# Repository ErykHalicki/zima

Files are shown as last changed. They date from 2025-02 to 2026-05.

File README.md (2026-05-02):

# Zima: Low-Cost Imitation Learning Robot

Zima is a custom-built rover with a 5-DOF arm, designed as a personal research platform for imitation learning in robotic manipulation. It uses teleoperated demonstrations to train vision-based policies that map camera observations directly to motor actions.

[Devlog](https://eryk.ca/zima_devlog.html) | [Dataset](https://huggingface.co/datasets/ehalicki/zima-rubiks-cube)


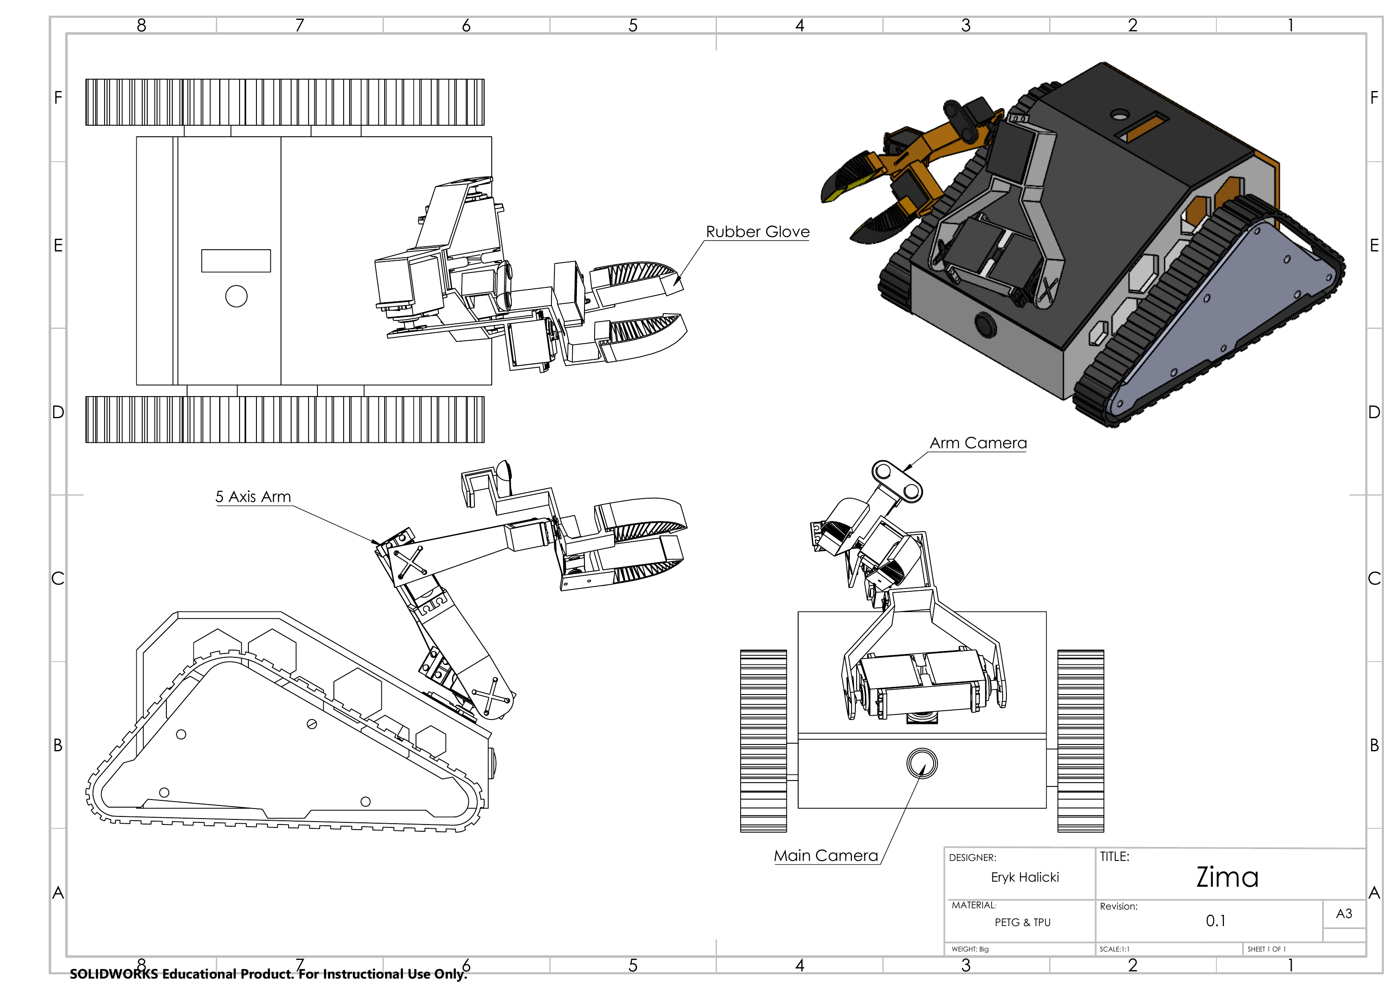
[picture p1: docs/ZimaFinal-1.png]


## Current Status
- Hardware prototype operational (5-DOF arm + tracked differential drive base)
- ROS2 control stack deployed on Raspberry Pi 5
- LeRobot integration for teleoperation, dataset recording, and training
- Training and evaluating manipulation policies (ACT, VLAs, world action models, etc.)
- Datasets hosted on HuggingFace with online visualization

## Hardware
- **Arm**: 4x MG996R servo joints + 1x gripper servo, custom forward/inverse kinematics solver
- **Base**: Modified Recon 6.0 Rover chassis, 2x DC motors with rotary encoders
- **Cameras**: Wrist-mounted + front-facing USB RGB (480x640)
- **Compute**: Raspberry Pi 5 (vision + policy execution), ESP32 (hardware interfacing)
- **CAD**: Custom 3D-printed parts designed in FreeCAD (`cad_models/`)

## Repository Structure
```
src/
  firmware/                              # ESP32 motor/servo control (Arduino)
  zima_ros2/
    zima_controls/                       # Arm kinematics solver & controller
    zima_hardware_integration/           # Serial, TCP, camera, and joystick interfaces
    zima_launch/                         # ROS2 launch configurations
    zima_msgs/                           # Custom message types (ArmStateDelta, MotorCommand, etc.)
  lerobot_robot_zima_robot/              # LeRobot Robot interface (TCP to hardware)
  lerobot_teleoperator_zima_ps3_teleop/  # PS3 gamepad teleoperator plugin
  scripts/                              # Bash scripts for recording, training, teleoperation
  legacy/                               # Deprecated ML/simulation code
cad_models/                             # FreeCAD design files
docs/                                   # Circuit diagrams
```

## Architecture

```
PS3 Controller ──► LeRobot Teleoperator ──► TCP ──► ROS2 (Pi 5) ──► Serial ──► ESP32 ──► Motors/Servos
                                                        │
                                                   Cameras ──► Observations
                                                        │
                                              LeRobot Dataset ──► HuggingFace Hub
                                                        │
                                                 Policy Training ──► Deployment
```

**Control flow**: The ESP32 handles low-level servo/motor control over serial. ROS2 nodes on the Pi manage kinematics, camera streaming, and a TCP server (port 5000) that bridges LeRobot to the hardware. The LeRobot framework handles teleoperation input, dataset recording, policy training, and inference.

**Kinematics**: Custom solver using YAML-defined link parameters, numerical IK with KD-tree initialization, and safety collision checks against predefined bounding boxes. Configuration in `src/zima_ros2/src/zima_controls/config/`.

## Usage

Teleoperate the robot:
```bash
lerobot-teleoperate --robot.type=zima_robot --robot.address=192.168.2.5
```

Record a dataset:
```bash
lerobot-record --robot.type=zima_robot --teleop.type=zima_ps3_teleop \
  --dataset.repo_id=ehalicki/zima-rubiks-cube --dataset.num_episodes=10
```

Train a policy:
```bash
lerobot-train --dataset.repo_id=ehalicki/zima-rubiks-cube \
  --policy.type=act --policy.device=mps
```

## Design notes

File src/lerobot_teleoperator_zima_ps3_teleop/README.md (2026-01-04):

# Zima PS3 Teleoperator

PS3 controller teleoperation interface for the Zima robot, compatible with the LeRobot framework.

## Installation

```bash
cd lerobot_teleoperator_zima_ps3_teleop
pip install -e .
```

## Usage

### With LeRobot CLI

```bash
lerobot-teleoperate \
    --robot.type=zima_robot \
    --robot.address=10.0.0.100 \
    --robot.port=5000 \
    --teleop.type=zima_ps3_teleop
```

### Control Scheme

The control scheme matches the ROS2 joy_control node exactly:

#### Track Control (D-Pad)
- **D-Pad Up**: Move forward
- **D-Pad Down**: Move backward
- **D-Pad Left**: Turn left
- **D-Pad Right**: Turn right

#### Arm Control (Analog Sticks)
- **Left Stick X-axis**: Arm position Y (left/right)
- **Left Stick Y-axis**: Arm position X (forward/back)
- **Right Stick X-axis**: Arm rotation X (roll, inverted)
- **Right Stick Y-axis**: Arm position Z (up/down)

#### Gripper Control
- **L2 Trigger**: Close gripper
- **R2 Trigger**: Open gripper

## Configuration Parameters

- `deadzone`: Analog stick deadzone (default: 0.15)
- `max_speed`: Maximum track speed multiplier (default: 1.0)
- `max_arm_delta`: Maximum arm position delta (default: 1.0)
- `max_rotation_delta`: Maximum arm rotation delta (default: 1.0)

## Requirements

- Python 3.10+
- LeRobot framework
- pygame (for gamepad support)
- PS3 controller (or compatible gamepad)

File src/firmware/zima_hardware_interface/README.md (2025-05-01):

# Zima Hardware Interface

## Overview

The Zima Hardware Interface is a modular Arduino sketch designed to control multiple hardware components for the Zima robotic platform, including:
- Servo Motors (8 channels)
- Rotary Encoders (2 channels)
- DC Motors (2 channels)

## Hardware Bootup Considerations

### EN Pin Capacitor Fix

**Important Hardware Modification:**
- Add a 1µF capacitor between EN and GND
- This resolves intermittent bootup issues with the ESP32
- Helps stabilize the chip during power-on sequence
- Prevents random boot failures or serial communication problems

#### Recommended Capacitor Specification
- Capacitance: 1 µF (microfarad)
- Voltage Rating: 6.3V or higher
- Type: Ceramic or Electrolytic

### Bootup Sequence Notes
- Ensure stable power supply
- Use the recommended EN pin capacitor
- Verify all connections before powering on

## Other Documentation Sections Remain the Same... 

(Rest of the previous README content)

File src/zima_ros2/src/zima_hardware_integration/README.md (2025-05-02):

# Hardware Integration Package

This package provides a ROS2 interface for the Zima robot hardware. It handles serial communication with the ESP32 microcontroller, converting between ROS2 messages and the serial command format used by the hardware interface.

## Architecture

The hardware integration is split into three nodes:

1. **Serial Receiver Node** (`serial_receiver`): Reads data from the serial port and publishes it as ROS2 messages
2. **Serial Sender Node** (`serial_sender`): Receives hardware commands and sends them to the hardware via serial port
3. **Command Generator Node** (`command_generator`): Converts high-level ROS2 messages (e.g., JointState) to hardware commands

## Message Types

The hardware integration uses custom message types defined in the `zima_msgs` package:

- `ServoCommand`: Command for a single servo motor
- `MotorCommand`: Command for DC motors (forward, reverse, stop)
- `EncoderData`: Data from wheel encoders
- `ServoPositions`: Current positions of all servo motors
- `HardwareCommand`: Low-level command for any hardware subsystem
- `HardwareStatus`: Status data from all hardware subsystems

## Usage

### Launch the Complete System

```bash
ros2 launch hardware_integration hardware_interface.py
```

### Launch with Custom Parameters

```bash
ros2 launch hardware_integration hardware_interface.py serial_port:=/dev/ttyACM0 baud_rate:=115200 update_rate:=100.0
```

### Running Individual Nodes

```bash
# Run the serial receiver node
ros2 run hardware_integration serial_receiver

# Run the serial sender node
ros2 run hardware_integration serial_sender

# Run the command generator node
ros2 run hardware_integration command_generator
```

## Topics

### Published Topics

- `/hardware_status` (zima_msgs/HardwareStatus): Complete hardware status
- `/encoder_data` (zima_msgs/EncoderData): Encoder data from wheels
- `/servo_positions` (zima_msgs/ServoPositions): Current servo positions

### Subscribed Topics

- `/joint_states` (sensor_msgs/JointState): Joint state commands for servos
- `/servo_command` (zima_msgs/ServoCommand): Direct servo commands
- `/motor_command` (zima_msgs/MotorCommand): DC motor commands
- `/hardware_command` (zima_msgs/HardwareCommand): Low-level hardware commands

## Parameters

- `serial_port` (string, default: '/dev/ttyUSB0'): Serial port for hardware communication
- `baud_rate` (int, default: 115200): Baud rate for serial communication
- `timeout` (double, default: 0.1): Serial read/write timeout in seconds
- `update_rate` (double, default: 50.0): Rate in Hz for reading from the serial port

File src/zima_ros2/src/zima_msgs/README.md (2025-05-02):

# Zima Messages Package

This package defines custom ROS2 message types for the Zima robot hardware interface.

## Message Types

### ServoCommand

Command for a single servo motor:
- `std_msgs/Header header`: Standard ROS header
- `uint8 servo_id`: ID of the servo (0-7)
- `float32 position`: Position in degrees (0-180)

### MotorCommand

Command for DC motors:
- `std_msgs/Header header`: Standard ROS header
- `uint8 motor_id`: Which motor (MOTOR_LEFT=0, MOTOR_RIGHT=1)
- `uint8 action`: Action (ACTION_FORWARD=0, ACTION_REVERSE=1, ACTION_STOP=2)
- `int32 speed`: Speed value (0-255 for forward/reverse, 0 or 1 for stop)

### EncoderData

Data from wheel encoders:
- `std_msgs/Header header`: Standard ROS header
- `int32 left_clicks`: Encoder clicks for left wheel
- `int32 right_clicks`: Encoder clicks for right wheel

### ServoPositions

Current positions of all servo motors:
- `std_msgs/Header header`: Standard ROS header
- `float32[] positions`: Current positions of all servos (array of 8 values)

### HardwareCommand

Low-level command for any hardware subsystem:
- `std_msgs/Header header`: Standard ROS header
- `uint8 subsystem`: The subsystem ID (0-13)
- `float32 value`: The command value

Subsystem mapping:
- 0-7: Servo motors (position in degrees)
- 8: Left DC Motor Forward (speed 0-255)
- 9: Left DC Motor Reverse (speed 0-255)
- 10: Left DC Motor Stop (0 or 1)
- 11: Right DC Motor Forward (speed 0-255)
- 12: Right DC Motor Reverse (speed 0-255)
- 13: Right DC Motor Stop (0 or 1)

### HardwareStatus

Status data from all hardware subsystems:
- `std_msgs/Header header`: Standard ROS header
- `int32 clicks_left`: Left encoder clicks
- `int32 clicks_right`: Right encoder clicks
- `float32[] servo_positions`: Array of 8 servo positions

## Usage

To use these messages in your ROS2 package, add a dependency in your `package.xml`:

```xml
<depend>zima_msgs</depend>
```

And include the message headers in your C++ code:

```cpp
#include "zima_msgs/msg/servo_command.hpp"
#include "zima_msgs/msg/motor_command.hpp"
// etc.
```

Or import them in your Python code:

```python
from zima_msgs.msg import ServoCommand, MotorCommand
# etc.
```

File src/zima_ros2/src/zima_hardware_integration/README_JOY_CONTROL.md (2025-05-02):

# Joystick Control for Zima Robot

This document describes how to use a PS3 controller to drive the Zima robot.

## Overview

The joystick control system uses the ROS2 `joy` package to receive controller input and converts it to motor commands for the Zima robot. The controller can be used to drive the robot in differential drive mode, where the left joystick controls both forward/backward movement and turning.

## Hardware Requirements

- PS3 compatible controller (or knockoff)
- USB connection or Bluetooth capability
- Zima robot with ESP32 running zima_hardware_interface

## Default Mappings

### Button Mappings
- **X Button**: Button 0
- **Circle Button**: Button 1
- **Triangle Button**: Button 2
- **Square Button**: Button 3
- **L1 Button**: Button 4
- **R1 Button**: Button 5
- **L2 Button**: Button 6
- **R2 Button**: Button 7
- **Select Button**: Button 8
- **Start Button**: Button 9
- **PS Button**: Button 10
- **L3 Button** (Left Stick Press): Button 11
- **R3 Button** (Right Stick Press): Button 12
- **D-Pad Up**: Button 13
- **D-Pad Down**: Button 14
- **D-Pad Left**: Button 15
- **D-Pad Right**: Button 16

### Axis Mappings
- **Left Stick X-Axis**: Axis 0 (left/right)
- **Left Stick Y-Axis**: Axis 1 (up/down)
- **L2 Trigger**: Axis 2 (-1 when pressed, 1 when released)
- **Right Stick X-Axis**: Axis 3 (left/right)
- **Right Stick Y-Axis**: Axis 4 (up/down)
- **R2 Trigger**: Axis 5 (-1 when pressed, 1 when released)

### Control Functions
- **Left Joystick**: Control movement (forward/backward/turning)
- **R1 Button**: Enable motor control (must be held down)
- **R2 Button**: Emergency stop (all motors)
- **Select Button**: Cycle through control modes (drive, arm, custom1, custom2)

## Installation

1. Make sure the ROS2 joy package is installed:
   ```bash
   sudo apt-get update
   sudo apt-get install ros-humble-joy
   ```

2. Build the package:
   ```bash
   cd ~/Desktop/zima/src/ros2_ws
   colcon build --packages-select hardware_integration
   source install/setup.bash
   ```

## Usage

1. Connect your PS3 controller to your computer via USB or Bluetooth
2. Verify the controller is detected:
   ```bash
   ls -l /dev/input/js*
   ```

3. Test your controller mapping (optional but recommended):
   ```bash
   ros2 launch hardware_integration joy_tester.py
   ```
   Press buttons and move joysticks to see their corresponding indices displayed in the terminal.

4. Launch the joystick control system:
   ```bash
   ros2 launch hardware_integration joy_control.py
   ```
   
5. Control your robot:
   - Hold down R1 (button 5) to enable movement control
   - Use the left joystick to drive the robot
   - Press R2 (button 7) for emergency stop
   - Press Select (button 8) to cycle through control modes

## Parameters

The following parameters can be configured when launching:

- `joy_dev`: Joystick device path (default: `/dev/input/js0`)
- `joy_deadzone`: Deadzone for joystick inputs (default: `0.05`)
- `max_speed`: Maximum motor speed (default: `255`)
- `serial_port`: Serial port for hardware communication (default: `/dev/ttyUSB0`)
- `baud_rate`: Baud rate for serial communication (default: `115200`)

Example with custom parameters:
```bash
ros2 launch hardware_integration joy_control.py joy_dev:=/dev/input/js1 max_speed:=200
```

## Node Details

### joy_control_node

This node subscribes to `/joy` topic and publishes to `/motor_command` topic. It performs the following:

1. Reads joystick inputs for linear and angular movement
2. Applies deadzone and scaling
3. Calculates differential drive values for left and right motors
4. Publishes appropriate MotorCommand messages

The node only sends commands when the enable button (R1) is pressed, providing a safety feature.

## Troubleshooting

1. **Controller not detected**: 
   - Check the device path with `ls -l /dev/input/js*`
   - Update the joy_dev parameter with the correct path

2. **Motors not responding**:
   - Verify that you're holding the R1 button while moving the joystick
   - Check that the serial connection is working
   - Ensure the ESP32 is powered and running the correct firmware

3. **Unexpected movement**:
   - Adjust the deadzone parameter if the robot moves when the stick is at rest
   - Reduce max_speed if the robot moves too quickly
   - Check the orientation of the controller (joystick axes may be different)

## Control Modes

The joystick controller supports multiple control modes that can be cycled through using the Select button:

### 1. Drive Mode (Default)
- **Left Joystick**: Controls differential drive movement
  - Y-axis: Forward/backward movement
  - X-axis: Left/right turning
- **R1 Button**: Must be held to enable movement (safety feature)
- **R2 Button**: Emergency stop

### 2. Arm Mode
Reserved for future arm control implementation. When implemented, this mode will allow:
- Controlling servo positions for robotic arm joints
- Precise positional control
- Grip control

### 3. Custom Mode 1
Reserved for future custom control implementation.

### 4. Custom Mode 2
Reserved for future custom control implementation.

## Extensibility

The control system is designed to be easily extended. The codebase includes empty function placeholders for:

- `process_arm_commands()`: For controlling robot arm servos
- `process_custom1_commands()` & `process_custom2_commands()`: For custom control schemes
- `handle_dpad_inputs()`: For D-pad control functions
- `handle_shape_buttons()`: For X, Circle, Triangle, Square button actions
- `handle_trigger_buttons()`: For secondary L1/L2/R1/R2 functions
- `handle_thumbstick_buttons()`: For L3/R3 button press actions

To extend functionality, edit the joy_control.py file and implement these functions according to your needs.

These can be added to the joy_control.py file by adding new parameters and updating the joy_callback method.

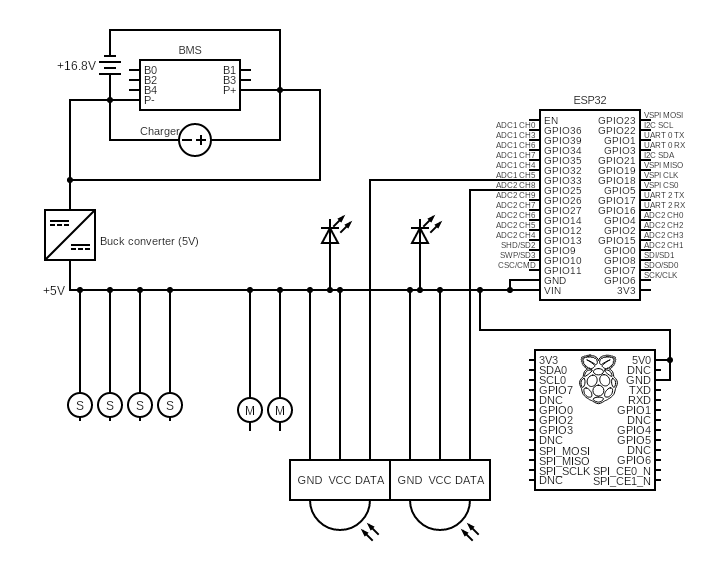
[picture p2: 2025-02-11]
docs/circuit.png

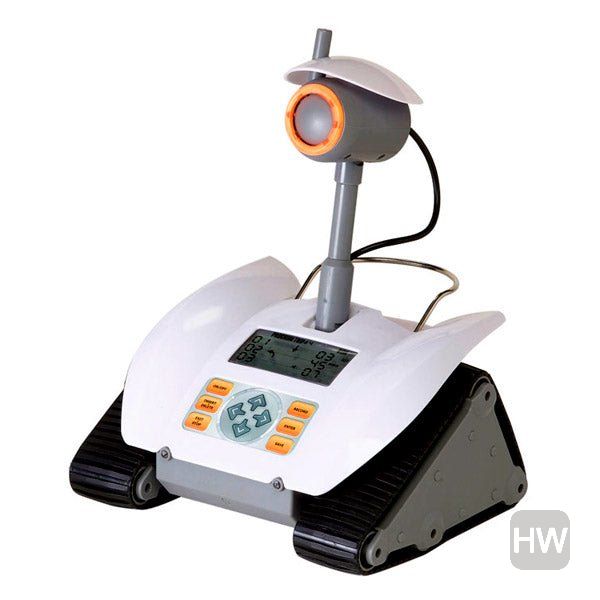
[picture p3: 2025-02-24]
docs/toy.jpeg

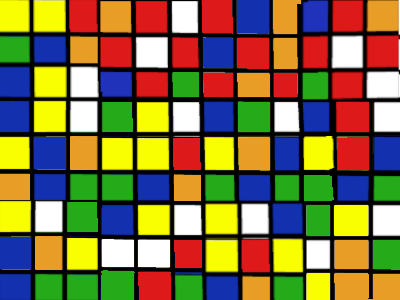
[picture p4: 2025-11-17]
src/imitation_learning/sim/scenes/textures/rubiks.png

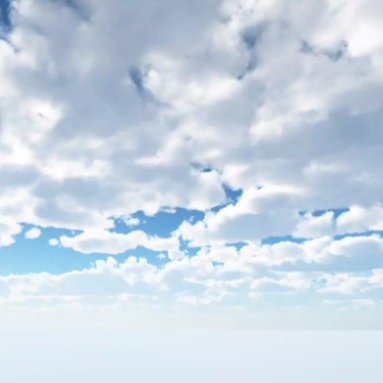
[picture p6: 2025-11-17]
src/imitation_learning/sim/scenes/textures/sky.png

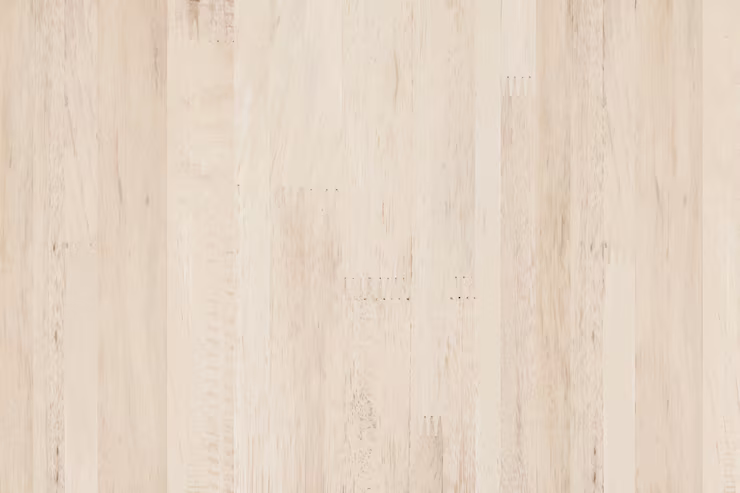
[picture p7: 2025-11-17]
src/imitation_learning/sim/scenes/textures/floorboard.png

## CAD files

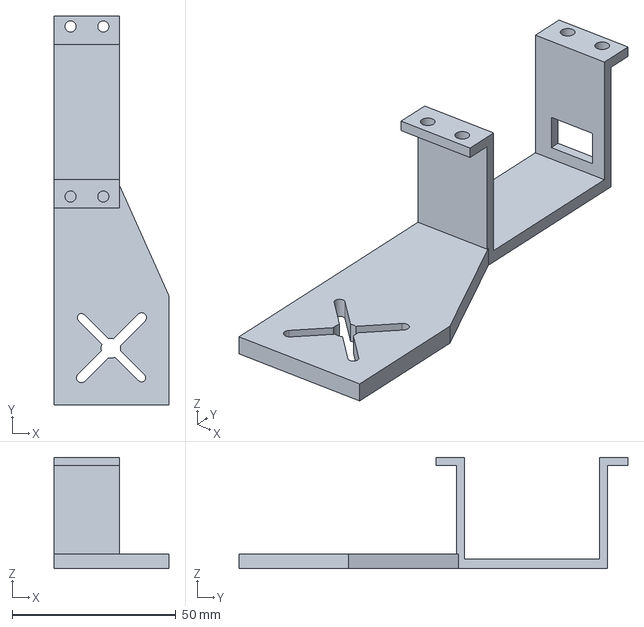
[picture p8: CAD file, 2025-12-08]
cad_models/zima_arm_elbow_to_wrist.FCStd
35.0 x 118.8 x 34.0 mm

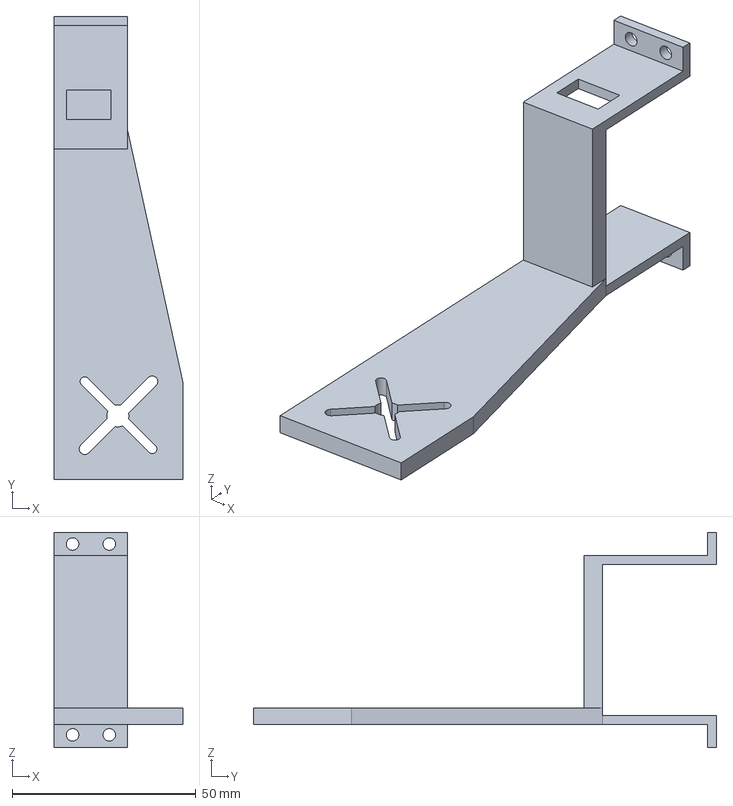
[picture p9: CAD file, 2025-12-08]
cad_models/zima_arm_wrist_to_handv2.FCStd
35.0 x 126.0 x 58.7 mm

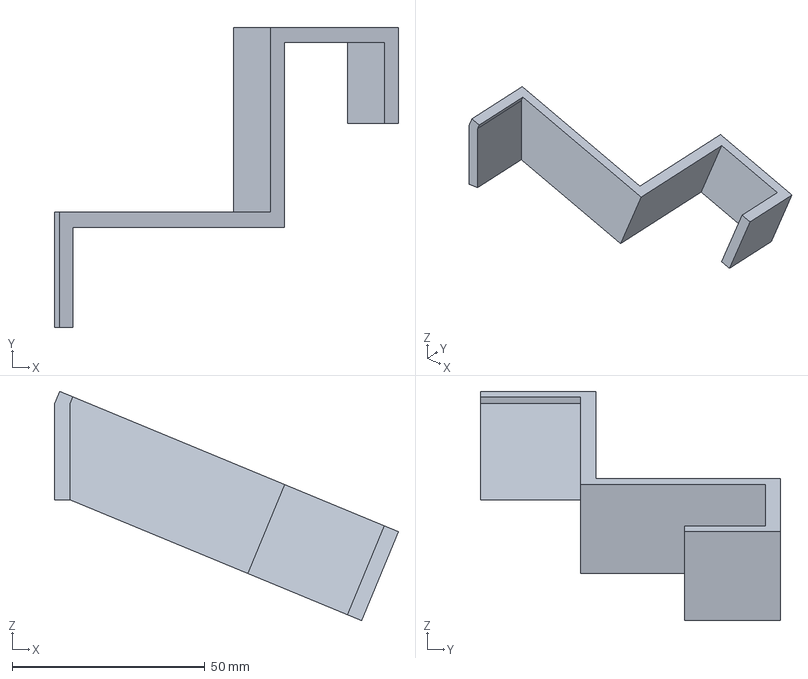
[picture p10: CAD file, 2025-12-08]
cad_models/zima_camera_mount.FCStd
89.4 x 78.0 x 59.6 mm

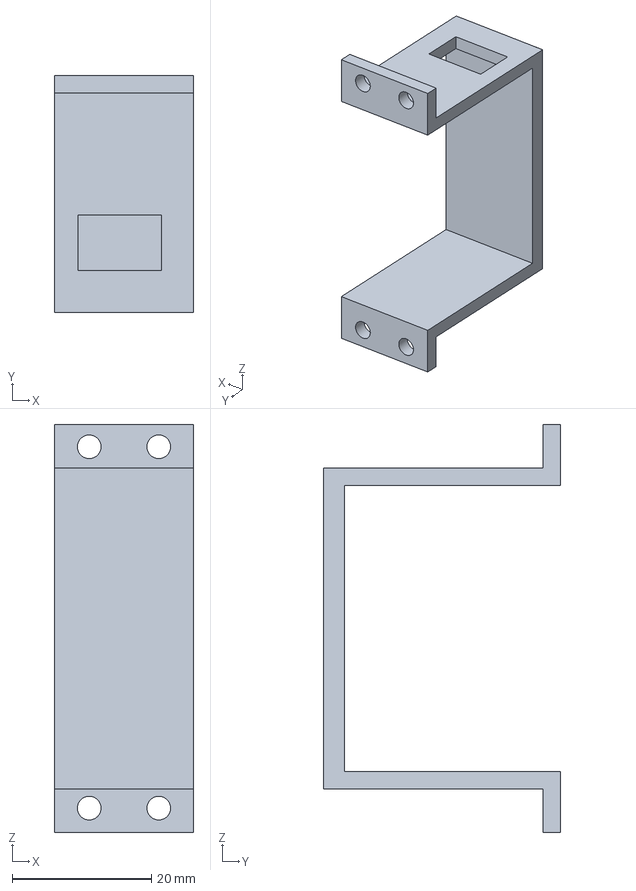
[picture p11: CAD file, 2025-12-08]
cad_models/996R_Mount.FCStd
20.0 x 34.0 x 58.7 mm

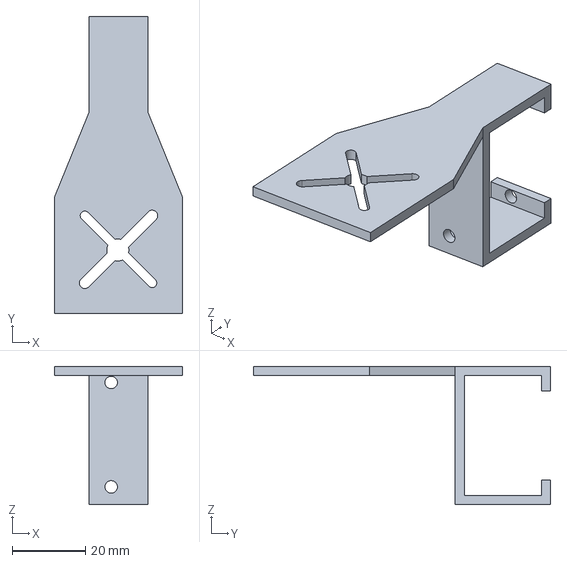
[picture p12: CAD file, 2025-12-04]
cad_models/zima_arm_wrist_to_hand.FCStd
35.0 x 81.0 x 37.7 mm

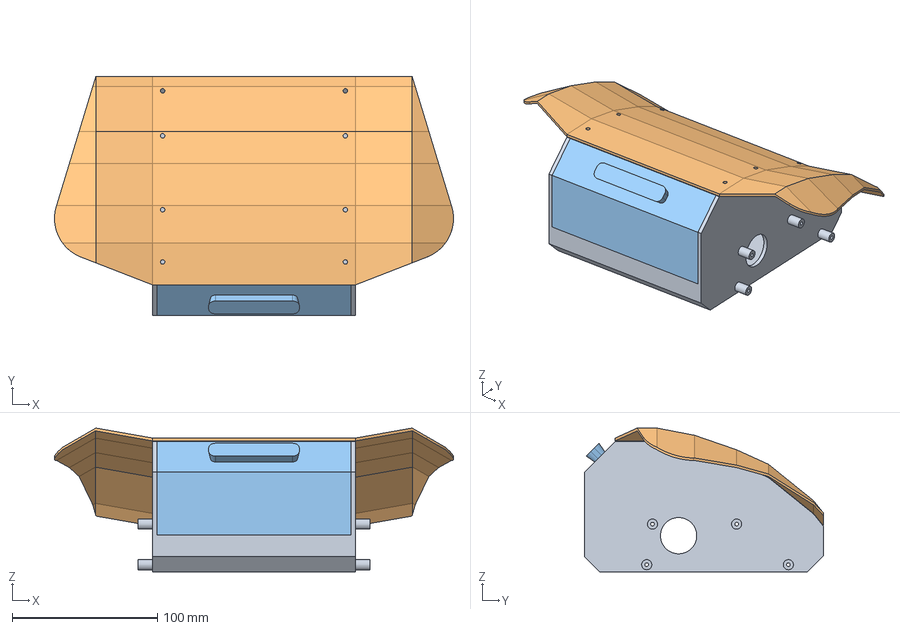
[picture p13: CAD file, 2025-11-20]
cad_models/zima_frameV1.FCStd
275.1 x 165.0 x 99.2 mm
Main Body
front panel
back panel

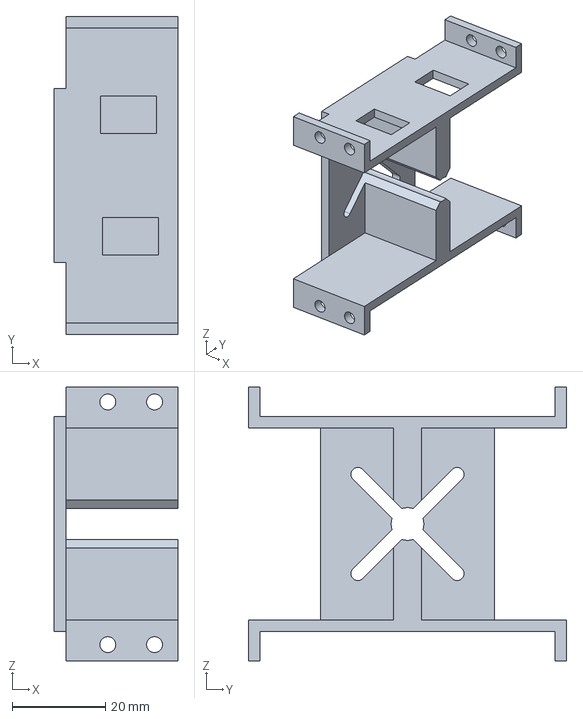
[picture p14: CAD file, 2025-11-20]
cad_models/zima_arm_shoulder.FCStd
26.5 x 68.1 x 58.7 mm

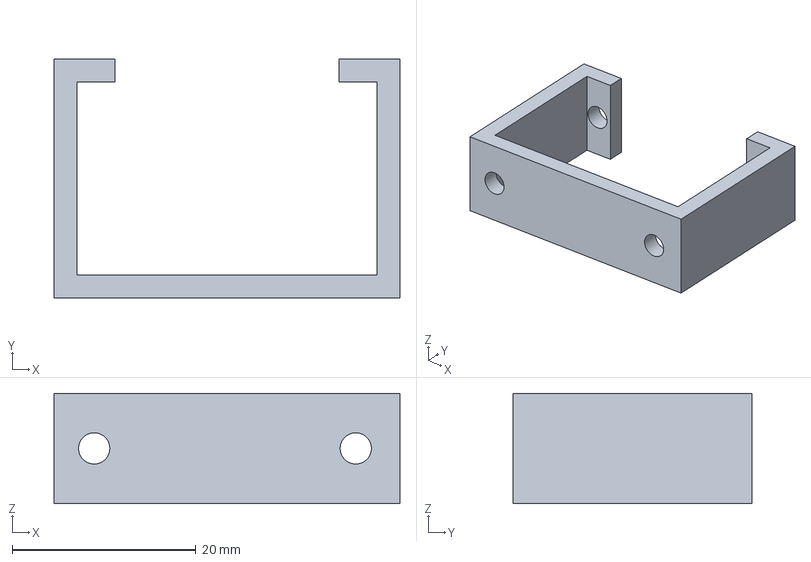
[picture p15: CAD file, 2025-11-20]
cad_models/90MG_Mount.FCStd
37.7 x 26.0 x 12.0 mm

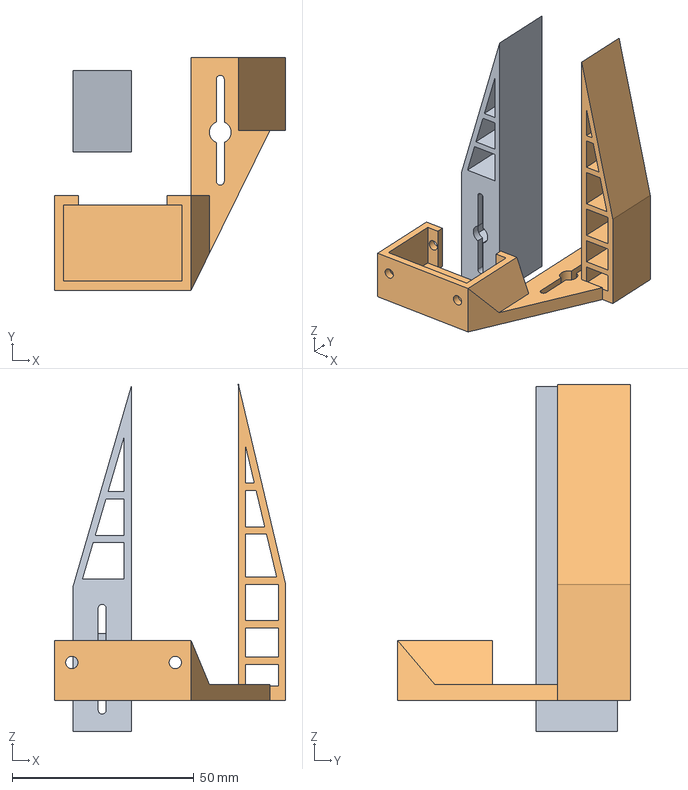
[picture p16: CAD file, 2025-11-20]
cad_models/zima_arm_hand_to_fingers.FCStd
63.7 x 64.0 x 95.5 mm

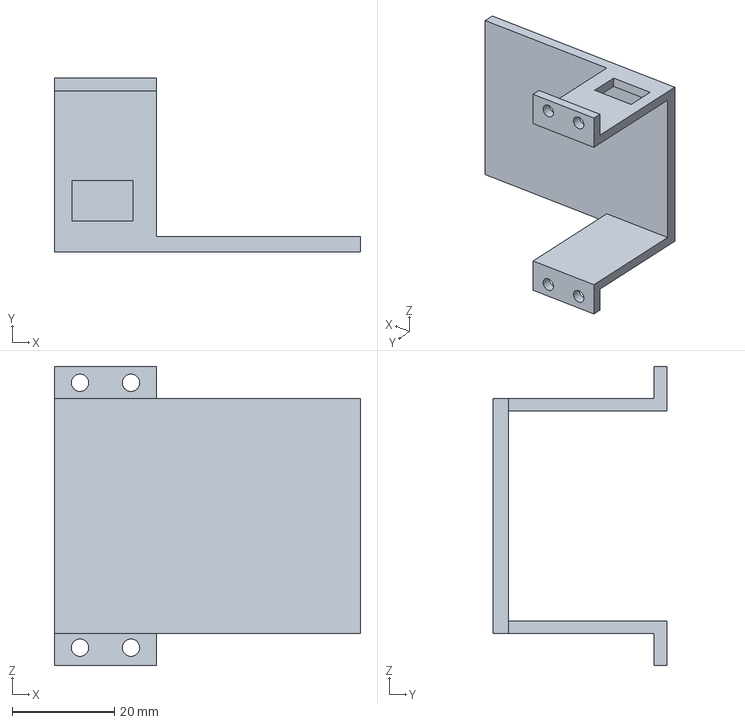
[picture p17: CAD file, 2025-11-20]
cad_models/zima_arm_test_base.FCStd
60.0 x 34.0 x 58.7 mm

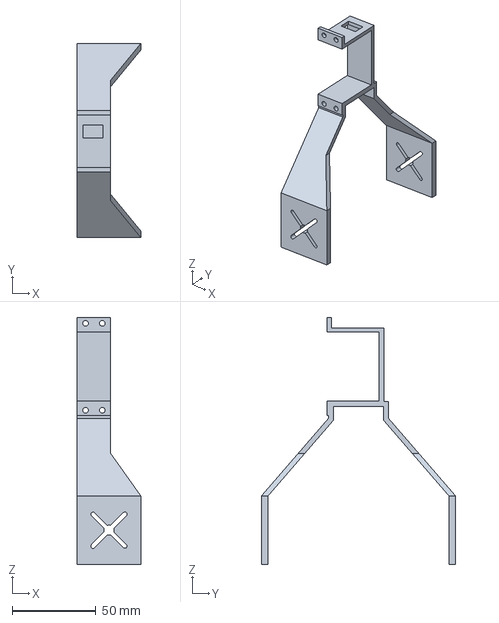
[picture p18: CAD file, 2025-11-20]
cad_models/zima_arm_shoulder_to_elbow.FCStd
38.0 x 116.0 x 147.6 mm

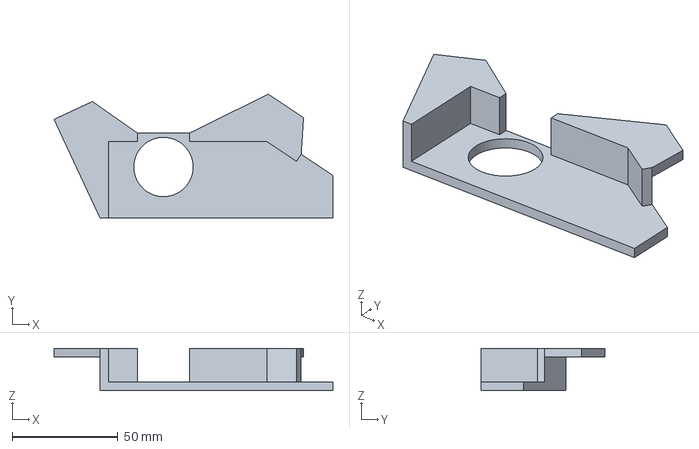
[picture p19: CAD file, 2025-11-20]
cad_models/zima_track_adaptor.FCStd
131.7 x 58.4 x 20.0 mm

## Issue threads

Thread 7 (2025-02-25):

Do reading preparation for robotic arm

ErykHalicki, 2025-02-25:
1. Foundation in Multimodal Learning
	•	Read:
	•	Multimodal Machine Learning: A Survey and Taxonomy (Baltrušaitis et al., 2018)
	•	Learning Transferable Visual Models From Natural Language Supervision (Radford et al., 2021) (CLIP paper)
	•	BLIP-2: Bootstrapped Language-Image Pre-training with Frozen Image Encoders and Large Language Models (Li et al., 2023)
	•	Do:
	•	Implement CLIP or BLIP from scratch using PyTorch.
	•	Experiment with contrastive learning for vision-language alignment.

2. Understanding Transformer Architectures
	•	Read:
	•	Attention Is All You Need (Vaswani et al., 2017) (Transformers)
	•	Scaling Laws for Neural Language Models (Kaplan et al., 2020)
	•	Hugging Face’s The Annotated Transformer
	•	Do:
	•	Fine-tune an LLM for captioning or instruction following (e.g., use LLaMA or GPT models).

3. Reinforcement Learning & Action Models
	•	Read:
	•	Reinforcement Learning: An Introduction (Sutton & Barto, 2018)
	•	Deep Reinforcement Learning with Python (Francois-Lavet et al., 2018)
	•	Scaling Robot Learning with Semantically Imagined Experience (James et al., 2023)
	•	Do:
	•	Implement PPO or SAC for robotic control using Stable Baselines3.
	•	Train a policy to map language commands to actions using imitation learning (e.g., BC or GAIL).

4. Vision-Language-Action Integration
	•	Read:
	•	SayCan: Grounding Language in Robotic Affordances (Ahn et al., 2022)
	•	PaLM-E: An Embodied Multimodal Language Model (Driess et al., 2023)
	•	RT-2: Vision-Language-Action Models Transfer Web Knowledge to Robotic Control (Brohan et al., 2023)
	•	Do:
	•	Implement a SayCan-inspired system with CLIP + RL.
	•	Replicate RT-2’s architecture using open-source LLMs.
	•	Train an agent in Habitat or Isaac Gym to follow text instructions.

5. Practical Experience with Robotics
	•	Read:
	•	Learning Agile Robotic Locomotion Skills by Imitating Animals (Peng et al., 2020)
	•	What Matters in Learning from Offline Human Demonstrations for Robot Manipulation (Singh et al., 2023)
	•	Do:
	•	Work with a real or simulated robot (UR5, Fetch, or A1) using PyBullet or Isaac Sim.
	•	Implement a pipeline where a user gives a text command, which is parsed into an action executed by a robot.

Closed 2025-04-24.

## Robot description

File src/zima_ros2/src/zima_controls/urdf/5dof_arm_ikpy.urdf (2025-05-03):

<?xml version="1.0"?>
<robot name="robot_arm">
  <!-- World Link (fixed frame) -->
  <link name="world">
    <visual>
      <geometry>
        <box size="0.001 0.001 0.001"/>
      </geometry>
    </visual>
  </link>
  
  <!-- Base Link -->
  <link name="base_link">
    <visual>
      <geometry>
        <cylinder radius="0.04" length="0.02"/>
      </geometry>
      <material name="base_color">
        <color rgba="0.2 0.2 0.2 1"/>
      </material>
    </visual>
    <collision>
      <geometry>
        <cylinder radius="0.04" length="0.02"/>
      </geometry>
    </collision>
    <inertial>
      <mass value="1.0"/>
      <inertia ixx="0.01" ixy="0.0" ixz="0.0" iyy="0.01" iyz="0.0" izz="0.01"/>
    </inertial>
  </link>
  
  <!-- Base Joint (rotates perpendicular to arm) -->
  <joint name="base_joint" type="revolute">
    <parent link="base_link"/>
    <child link="shoulder_link"/>
    <origin xyz="0 0 0.01" rpy="0 0.46 0"/>
    <axis xyz="0 0 1"/>
    <limit lower="-1.57" upper="1.57" effort="100" velocity="1.0"/>
  </joint>

  <!-- Shoulder Link -->
  <link name="shoulder_link">
    <visual>
      <geometry>
        <box size="0.04 0.04 0.02"/>
      </geometry>
      <material name="shoulder_color">
        <color rgba="0.8 0.2 0.2 1"/>
      </material>
    </visual>
    <collision>
      <geometry>
        <box size="0.04 0.04 0.02"/>
      </geometry>
    </collision>
    <inertial>
      <mass value="0.5"/>
      <inertia ixx="0.001" ixy="0.0" ixz="0.0" iyy="0.001" iyz="0.0" izz="0.001"/>
    </inertial>
  </link>

  <!-- Shoulder Joint (rotates in line with arm) -->
  <joint name="shoulder_joint" type="revolute">
    <parent link="shoulder_link"/>
    <child link="upper_arm_link"/>
    <origin xyz="0 0 0.01" rpy="0 0 0"/>
    <axis xyz="0 1 0"/>
    <limit lower="-1.57" upper="1.57" effort="100" velocity="1.0"/>
  </joint>

  <!-- Upper Arm Link -->
  <link name="upper_arm_link">
    <visual>
      <origin xyz="0 0 0.06" rpy="0 0 0"/>
      <geometry>
        <box size="0.03 0.03 0.12"/>
      </geometry>
      <material name="arm_color">
        <color rgba="0.2 0.8 0.2 1"/>
      </material>
    </visual>
    <collision>
      <origin xyz="0 0 0.06" rpy="0 0 0"/>
      <geometry>
        <box size="0.03 0.03 0.12"/>
      </geometry>
    </collision>
    <inertial>
      <origin xyz="0 0 0.06" rpy="0 0 0"/>
      <mass value="0.3"/>
      <inertia ixx="0.001" ixy="0.0" ixz="0.0" iyy="0.001" iyz="0.0" izz="0.0005"/>
    </inertial>
  </link>

  <!-- Elbow Joint (in line with arm) -->
  <joint name="elbow_joint" type="revolute">
    <parent link="upper_arm_link"/>
    <child link="forearm_link"/>
    <origin xyz="0 0 0.12" rpy="0 0 0"/>
    <axis xyz="0 1 0"/>
    <limit lower="-1.57" upper="1.57" effort="100" velocity="1.0"/>
  </joint>

  <!-- Forearm Link -->
  <link name="forearm_link">
    <visual>
      <origin xyz="0 0 0.05" rpy="0 0 0"/>
      <geometry>
        <box size="0.025 0.025 0.10"/>
      </geometry>
      <material name="forearm_color">
        <color rgba="0.2 0.2 0.8 1"/>
      </material>
    </visual>
    <collision>
      <origin xyz="0 0 0.05" rpy="0 0 0"/>
      <geometry>
        <box size="0.025 0.025 0.10"/>
      </geometry>
    </collision>
    <inertial>
      <origin xyz="0 0 0.05" rpy="0 0 0"/>
      <mass value="0.2"/>
      <inertia ixx="0.0005" ixy="0.0" ixz="0.0" iyy="0.0005" iyz="0.0" izz="0.0001"/>
    </inertial>
  </link>

  <!-- Hand Joint (in line with arm) -->
  <joint name="hand_joint" type="revolute">
    <parent link="forearm_link"/>
    <child link="hand_link"/>
    <origin xyz="0 0 0.10" rpy="0 0 0"/>
    <axis xyz="0 1 0"/>
    <limit lower="-1.57" upper="1.57" effort="100" velocity="1.0"/>
  </joint>

  <!-- Hand Link -->
  <link name="hand_link">
    <visual>
      <origin xyz="0 0 0.04" rpy="0 0 0"/>
      <geometry>
        <box size="0.02 0.02 0.08"/>
      </geometry>
      <material name="hand_color">
        <color rgba="0.8 0.8 0.2 1"/>
      </material>
    </visual>
    <collision>
      <origin xyz="0 0 0.04" rpy="0 0 0"/>
      <geometry>
        <box size="0.02 0.02 0.08"/>
      </geometry>
    </collision>
    <inertial>
      <origin xyz="0 0 0.04" rpy="0 0 0"/>
      <mass value="0.1"/>
      <inertia ixx="0.0001" ixy="0.0" ixz="0.0" iyy="0.0001" iyz="0.0" izz="0.00005"/>
    </inertial>
  </link>

  <!-- Wrist Joint (perpendicular to arm) -->
  <joint name="wrist_joint" type="revolute">
    <parent link="hand_link"/>
    <child link="gripper_link"/>
    <origin xyz="0 0 0.08" rpy="0 0 0"/>
    <axis xyz="0 0 1"/>
    <limit lower="-1.57" upper="1.57" effort="100" velocity="1.0"/>
  </joint>

  <!-- Gripper Link -->
  <link name="gripper_link">
    <visual>
      <geometry>
        <box size="0.02 0.06 0.01"/>
      </geometry>
      <material name="gripper_color">
        <color rgba="0.5 0.5 0.5 1"/>
      </material>
    </visual>
    <collision>
      <geometry>
        <box size="0.02 0.06 0.01"/>
      </geometry>
    </collision>
    <inertial>
      <mass value="0.05"/>
      <inertia ixx="0.00001" ixy="0.0" ixz="0.0" iyy="0.00001" iyz="0.0" izz="0.00001"/>
    </inertial>
  </link>

  <!-- End effector frame for IK targets -->
  <joint name="gripper_to_end_effector" type="fixed">
    <parent link="gripper_link"/>
    <child link="end_effector"/>
    <origin xyz="0 0 0.01" rpy="0 0 0"/>
  </joint>

  <link name="end_effector">
    <visual>
      <geometry>
        <sphere radius="0.005"/>
      </geometry>
      <material name="end_effector_color">
        <color rgba="1.0 0.0 0.0 1"/>
      </material>
    </visual>
  </link>
</robot>

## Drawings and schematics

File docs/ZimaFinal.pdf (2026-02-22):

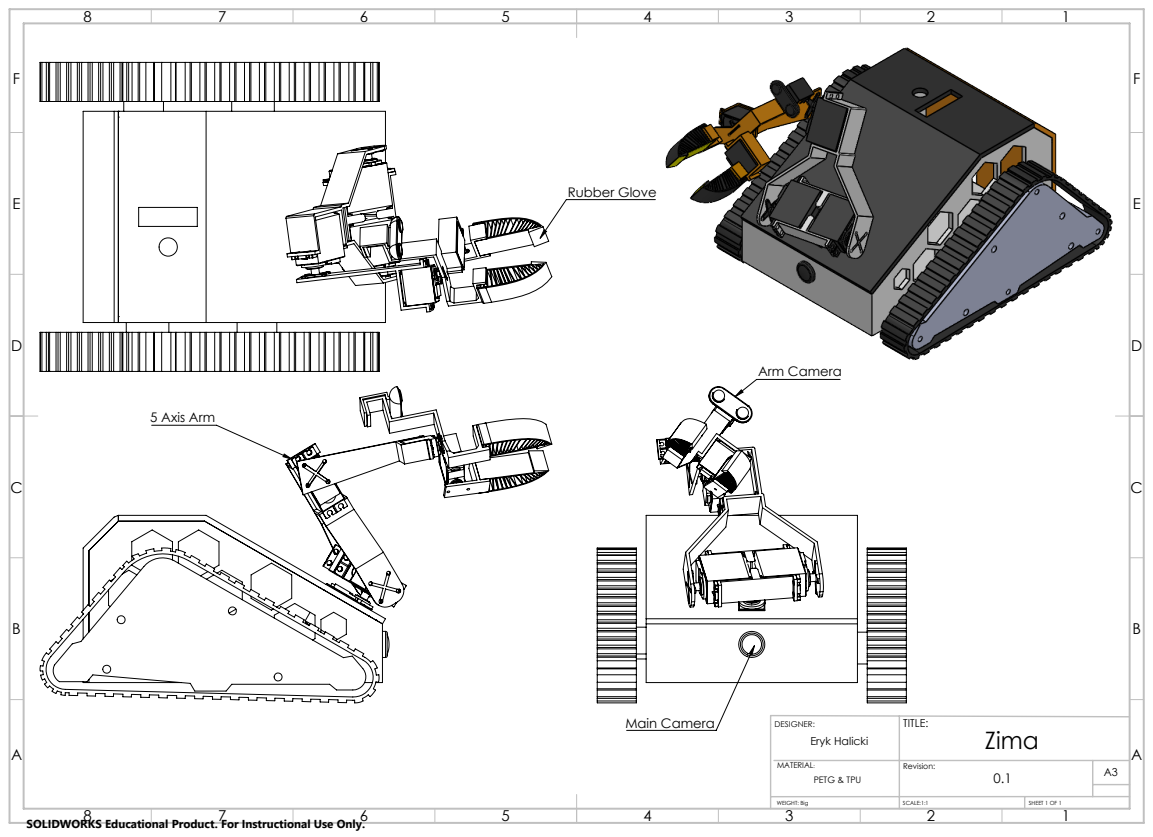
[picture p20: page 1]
5 Axis Arm; Rubber Glove; Arm Camera; Main Camera; A3 PETG & TPU

DESIGNER: Eryk Halicki MATERIAL: | TITLE: Zima

WEIGHT: Big | SCALE:1:1 | SHEET 1 OF 1

SOLIDWORKS Educational Product. For Instructional Use Only.

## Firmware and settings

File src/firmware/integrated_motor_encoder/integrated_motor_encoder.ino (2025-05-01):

#include <ESP32Servo.h>

// Rotary Encoder Configuration
#define ENCODER_PIN_LEFT 13   // Left encoder pin
#define ENCODER_PIN_RIGHT 14  // Right encoder pin

// Encoder Tracking Variables
unsigned long lastPulseTimeLeft = 0;
unsigned long lastPulseTimeRight = 0;
int lastStateLeft = HIGH;
int lastStateRight = HIGH;
unsigned long debounceDelay = 5;  // 5ms debounce time

// Clicks tracking
volatile long clicksLeft = 0;
volatile long clicksRight = 0;

// Servo Motor Configuration
const int minUs = 1000;
const int maxUs = 2000;
int pins[] = {16, 27, 25, 14, 26, 18, 17, 19};
float pos[] = {-1,-1,-1,-1,-1,-1,-1,-1};
float goal[] = {-1,-1,-1,-1,-1,-1,-1,-1};
float speed = 0.25;
Servo motors[8];

void IRAM_ATTR handleEncoderLeft() {
  // Interrupt handler for left encoder
  unsigned long currentTime = millis();
  if ((currentTime - lastPulseTimeLeft) > debounceDelay) {
    clicksLeft++;
    lastPulseTimeLeft = currentTime;
  }
}

void IRAM_ATTR handleEncoderRight() {
  // Interrupt handler for right encoder
  unsigned long currentTime = millis();
  if ((currentTime - lastPulseTimeRight) > debounceDelay) {
    clicksRight++;
    lastPulseTimeRight = currentTime;
  }
}

void setup() {
  // Rotary Encoder Setup
  pinMode(ENCODER_PIN_LEFT, INPUT_PULLUP);
  pinMode(ENCODER_PIN_RIGHT, INPUT_PULLUP);
  
  // Attach interrupt handlers
  attachInterrupt(digitalPinToInterrupt(ENCODER_PIN_LEFT), handleEncoderLeft, FALLING);
  attachInterrupt(digitalPinToInterrupt(ENCODER_PIN_RIGHT), handleEncoderRight, FALLING);
  
  // Servo Motor Setup
  for (int i = 0; i < 8; i++) {
    motors[i] = Servo();
    motors[i].setPeriodHertz(50);
  }

  Serial.begin(115200);
  Serial.println("ZIMA:INIT:MOTOR_ENCODER_INTEGRATED");
}

int sign(int i) {
  return (i < 0) ? -1 : 1;
}

const byte numChars = 64;
char receivedChars[numChars];
boolean newData = false;

void recvWithEndMarker() {
    static byte ndx = 0;
    char endMarker = '\n';
    char rc;
    
    if (Serial.available() > 0) {
        rc = Serial.read();

        if (rc != endMarker) {
            receivedChars[ndx] = rc;
            ndx++;
            if (ndx >= numChars) {
                ndx = numChars - 1;
            }
        }
        else {
            receivedChars[ndx] = '\0'; 
            ndx = 0;
            newData = true;
        }
    }
}

int currMotor = 0;
void parseNewData() {
    char * strtokIndx;

    strtokIndx = strtok(receivedChars, "<");
    currMotor = atoi(strtokIndx);

    strtokIndx = strtok(NULL, "<");
    if (currMotor < 8) {
      goal[currMotor] = atof(strtokIndx);
      
      // Special handling for specific motor groups
      if (currMotor == 2 || currMotor == 1) {
        goal[2] = goal[currMotor];
        goal[1] = 180 - goal[2];
        if (goal[2] == -1 || goal[1] == -1) {
          goal[1] = -1;
          goal[2] = -1;
        }
      }

      if (currMotor == 6 || currMotor == 7) {
        goal[7] = goal[currMotor];
        goal[6] = 180 - goal[7];
      }

      if (currMotor == 4) {
        if (goal[currMotor] != -1)
          goal[currMotor] = 180 - goal[currMotor];
      }
    }
    newData = false;
}

void updateMotors() {
  for (int i = 0; i < 8; i++) {
    if (goal[i] != -1 && pos[i] == -1) {
      motors[i].attach(pins[i]);
      pos[i] = goal[i];
    }
    if (goal[i] == -1 && pos[i] != -1) {
      motors[i].detach();
      pos[i] = -1;
    }
  }
  
  if (pos[2] != -1)
    pos[1] = 180 - pos[2];
  
  for (int i = 0; i < 8; i++) {
    if (pos[i] != -1) {
      motors[i].write(pos[i]);
      if (pos[i] + speed > goal[i] || pos[i] - speed < goal[i]) {
        pos[i] += sign(goal[i] - pos[i]) * speed;  
      }
      else {
        pos[i] = goal[i];
      }
    }
  }
}

void reportStatus() {
  // Formatted output for ROS2 Serial Parser
  Serial.print("ZIMA:DATA:");
  
  // Encoder Data
  Serial.print("CLICKSLEFT=");
  Serial.print(clicksLeft);
  Serial.print(",CLICKSRIGHT=");
  Serial.print(clicksRight);
  Serial.print(",");
  
  // Motor Positions
  Serial.print("MOTORS=");
  for (int i = 0; i < 8; i++) {
    Serial.print(pos[i]);
    if (i < 7) Serial.print("|");
  }
  Serial.println();

  // Reset clicks after reporting (optional, depends on your use case)
  // Uncomment if you want to track incremental clicks
  // clicksLeft = 0;
  // clicksRight = 0;
}

void loop() {
  // Check for Serial Input
  recvWithEndMarker();
  if (newData) parseNewData();
  
  // Update Motor Positions
  updateMotors();
  
  // Report System Status
  reportStatus();
  
  delay(10);  // Small delay to avoid excessive processing
}

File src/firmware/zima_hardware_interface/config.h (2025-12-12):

#ifndef ZIMA_HARDWARE_CONFIG_H
#define ZIMA_HARDWARE_CONFIG_H

// Servo Motor Configuration
#define SERVO_COUNT 8
const int SERVO_PINS[] = {16, 27, 25, 14, 26, 18, 17, 19};

// Rotary Encoder Configuration
#define ENCODER_PIN_LEFT 35   // Left encoder pin
#define ENCODER_PIN_RIGHT 34  // Right encoder pin

// DC Motor Configuration
#define DCMOTOR_LEFT_PINA 22
#define DCMOTOR_LEFT_PINB 23
#define DCMOTOR_RIGHT_PINA 2
#define DCMOTOR_RIGHT_PINB 15

#define DCMOTOR_RES 8
#define DCMOTOR_FREQ 5000

// Serial Communication
#define SERIAL_BAUD 115200
#define STATUS_REPORT_RATE 100   // Hz (status updates per second)

// Timing and Debounce
#define ENCODER_DEBOUNCE_DELAY 5  // ms

// Servo Motor Movement Speed
#define SERVO_SPEED 100         // Degrees per second

#endif // ZIMA_HARDWARE_CONFIG_H

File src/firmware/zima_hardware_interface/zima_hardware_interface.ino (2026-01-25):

#include <ESP32Servo.h>
#include "config.h"
#include "servo_control.h"
#include "encoder_control.h"
#include "dcmotor_control.h"

ServoController servoController;
EncoderController& encoderController = EncoderController::getInstance();
DCMotorController dcMotorController;

const byte numChars = 64;
char receivedChars[numChars];
boolean newData = false;

// Timing control for status reports
unsigned long lastStatusTime = 0;
unsigned long lastServoUpdate = 0;
const unsigned long statusInterval = 1000000 / STATUS_REPORT_RATE; // microseconds


void setup() {
  Serial.begin(SERIAL_BAUD);

  // Initialize subsystems
  servoController.init();
  encoderController.init();
  dcMotorController.init();
  
  // Initialize timing
  lastStatusTime = micros();

  Serial.println("ZIMA:INIT:HARDWARE_INTERFACE");
}

void recvWithEndMarker() {
    static byte ndx = 0;
    char endMarker = '\n';
    char rc;
    
    if (Serial.available() > 0) {
        rc = Serial.read();

        if (rc != endMarker) {
            receivedChars[ndx] = rc;
            ndx++;
            if (ndx >= numChars) {
                ndx = numChars - 1;
            }
        }
        else {
            receivedChars[ndx] = '\0'; 
            ndx = 0;
            newData = true;
        }
    }
}

void parseNewData() {
    char * strtokIndx;

    strtokIndx = strtok(receivedChars, "<");
    int subsystem = atoi(strtokIndx);

    strtokIndx = strtok(NULL, "<");
    float value = atof(strtokIndx);

    switch(subsystem) {
        case 0 ... 7:  // Servo motors
            servoController.setGoal(subsystem, value);
            break;
        case 8:  // Left DC Motor Forward
            dcMotorController.leftMotorForward(static_cast<int>(value));
            break;
        case 9:  // Left DC Motor Reverse
            dcMotorController.leftMotorReverse(static_cast<int>(value));
            break;
        case 10:  // Left DC Motor Stop
            dcMotorController.leftMotorStop(value > 0);
            break;
        case 11:  // Right DC Motor Forward
            dcMotorController.rightMotorForward(static_cast<int>(value));
            break;
        case 12:  // Right DC Motor Reverse
            dcMotorController.rightMotorReverse(static_cast<int>(value));
            break;
        case 13:  // Right DC Motor Stop
            dcMotorController.rightMotorStop(value > 0);
            break;
    }
}

void reportStatus() {
    Serial.print("ZIMA:DATA:");
    
    // Encoder Data
    Serial.print("CLICKSLEFT=");
    Serial.print(encoderController.getLeftClicks());
    Serial.print(",CLICKSRIGHT=");
    Serial.print(encoderController.getRightClicks());
    Serial.print(",");
    
    // Motor Positions
    Serial.print("SERVOS=");
    float* positions = servoController.getPositions();
    for (int i = 0; i < 8; i++) {
        Serial.print(positions[i]);
        if (i < 7) Serial.print("|");
    }
    Serial.println();
}

void loop() {
    // Check for Serial Input
    recvWithEndMarker();
    if (newData) {
        parseNewData();
        newData = false;
    }

    unsigned long currentTime = micros();
    
    // Update Motor Positions
    if ( currentTime - lastServoUpdate >= 20000 ){
        servoController.updatePositions();
        lastServoUpdate = currentTime;
    }
    
    // Report System Status at specified rate
    if (currentTime - lastStatusTime >= statusInterval) {
        reportStatus();
        lastStatusTime = currentTime;
    }
    
    // No delay, clear serial buffer as fast as possible
}

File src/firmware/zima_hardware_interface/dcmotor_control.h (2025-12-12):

#ifndef ZIMA_DCMOTOR_CONTROL_H
#define ZIMA_DCMOTOR_CONTROL_H

#include <ESP32Servo.h>
#include "config.h"

class DCMotorController {
private:
    ESP32PWM pwmLeft1;
    ESP32PWM pwmLeft2;
    ESP32PWM pwmRight1;
    ESP32PWM pwmRight2;
    
    int leftPin1;
    int leftPin2;
    int rightPin1;
    int rightPin2;
    
    int maxPwmValue;

public:
    DCMotorController() : 
        leftPin1(DCMOTOR_LEFT_PINA),
        leftPin2(DCMOTOR_LEFT_PINB),
        rightPin1(DCMOTOR_RIGHT_PINA),
        rightPin2(DCMOTOR_RIGHT_PINB)
    {
        // Calculate max PWM value based on resolution
        maxPwmValue = (1 << DCMOTOR_RES) - 1; // 2^DCMOTOR_RES - 1
    }

    void init() {
        // Set up PWM frequency and resolution for all motor pins
        pwmLeft1.attachPin(leftPin1, DCMOTOR_FREQ, DCMOTOR_RES);
        pwmLeft2.attachPin(leftPin2, DCMOTOR_FREQ, DCMOTOR_RES);
        pwmRight1.attachPin(rightPin1, DCMOTOR_FREQ, DCMOTOR_RES);
        pwmRight2.attachPin(rightPin2, DCMOTOR_FREQ, DCMOTOR_RES);
        
        // Initialize all PWM to 0
        pwmLeft1.write(0);
        pwmLeft2.write(0);
        pwmRight1.write(0);
        pwmRight2.write(0);
    }

    void leftMotorForward(int speed) {
        speed = constrain(speed, 0, 255);
        // Map 0-255 range to max PWM value
        int pwmValue = map(speed, 0, 255, 0, maxPwmValue);
        pwmLeft1.write(pwmValue);
        pwmLeft2.write(0);
    }

    void leftMotorReverse(int speed) {
        speed = constrain(speed, 0, 255);
        // Map 0-255 range to max PWM value
        int pwmValue = map(speed, 0, 255, 0, maxPwmValue);
        pwmLeft1.write(0);
        pwmLeft2.write(pwmValue);
    }

    void rightMotorForward(int speed) {
        speed = constrain(speed, 0, 255);
        // Map 0-255 range to max PWM value
        int pwmValue = map(speed, 0, 255, 0, maxPwmValue);
        pwmRight1.write(pwmValue);
        pwmRight2.write(0);
    }

    void rightMotorReverse(int speed) {
        speed = constrain(speed, 0, 255);
        // Map 0-255 range to max PWM value
        int pwmValue = map(speed, 0, 255, 0, maxPwmValue);
        pwmRight1.write(0);
        pwmRight2.write(pwmValue);
    }

    void leftMotorStop(bool softStop = true) {
        if (softStop) {
            // Soft stop - just set PWM to 0
            pwmLeft1.write(0);
            pwmLeft2.write(0);
        } else {
            // Hard brake - set both channels to max
            pwmLeft1.write(maxPwmValue);
            pwmLeft2.write(maxPwmValue);
        }
    }

    void rightMotorStop(bool softStop = true) {
        if (softStop) {
            // Soft stop - just set PWM to 0
            pwmRight1.write(0);
            pwmRight2.write(0);
        } else {
            // Hard brake - set both channels to max
            pwmRight1.write(maxPwmValue);
            pwmRight2.write(maxPwmValue);
        }
    }
};

#endif // ZIMA_DCMOTOR_CONTROL_H

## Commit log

2025-02-24 arduino motor control code
2025-03-03 added multiplie servo control
2025-03-10 arm prototype complete
    [robot.urdf]
2025-03-10 semi working inverse kinematics
    [robot.urdf]
2025-03-10 semi working inverse kinematics what
    [robot.urdf]
2025-04-22 servo control test changes
2025-05-01 Update integrated motor encoder with two-encoder click tracking support
    - Added support for two rotary encoders
    - Replaced RPM tracking with click counting
    - Implemented hardware interrupts for precise tracking
    - Maintained existing motor control functionality
    - Updated serial output format to report encoder clicks
    [integrated_motor_encoder.ino]
2025-05-01 Update DC motor control to use FS_MX1508 library
    - Replaced ESP32MX1508 with FS_MX1508
    - Added init() method for DC motor configuration
    - Updated README with library transition notes
    - Simplified motor control implementation
    [dcmotor_control.h, zima_hardware_interface.ino]
2025-05-01 Resolve ESP32 interrupt handler relocation issues
    - Moved interrupt handlers to global functions
    - Used global variables for click tracking
    - Simplified interrupt logic
    - Maintained singleton EncoderController interface
    [encoder_control.h]
2025-05-01 Update motor control method names and pin configurations
    - Replace drive -> motorGo
    - Replace brake -> motorBrake
    - Update DC motor pin configurations
    [config.h, dcmotor_control.h]
2025-05-01 Document EN pin capacitor fix for ESP32 bootup stability
    - Add hardware modification details to project README
    - Update hardware interface README with bootup considerations
    - Provide specific capacitor recommendations
    - Explain the purpose of the 1µF capacitor between EN and GND
2025-05-01 Update hardware interface, encoder control, and IK solver
    - Modify main loop delay in config.h
    - Enhance zima_hardware_interface with more granular motor control
    - Improve IK solver iteration parameters
    - Remove integrated_motor_encoder (deprecated)
    - Optimize motor and encoder control logic
2025-05-02 Move servo speed to config.h as a configurable constant
    - Add SERVO_SPEED definition in config.h
    - Update servo_control.h to use the new constant
    - Add comment explaining speed range
2025-05-02 updated dc motor control to use esp32 servo
2025-05-03 fixed input command lag and status update rate
    [config.h, servo_control.h, zima_hardware_interface.ino]
2025-05-03 servo speed config change
2025-05-03 set up ikpy and improved urdf
    [robot_arm_ikpy.urdf]
2025-05-04 creating inverse kinematics pipeline
2025-05-04 added fallback orientation modes for ik solver
    [robot_arm_ikpy.urdf]
2025-05-08 added arm controller testing command
2025-05-23 workspace renaming
    [robot.urdf, robot_arm_ikpy.urdf]
2025-05-23 gripper command working
2025-11-03 added camera hardware test
2025-11-07 added keyboard control and camera
2025-11-19 added ros2 nn_controller + cleaning up ros2 workspace
    [robot.urdf, robot_arm_ikpy.urdf]
2025-11-19 camera driver addition
2025-11-20 added CAD models
    [90MG_Mount.FCStd, 996R_Mount.FCStd, robot.urdf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]
2025-11-22 reducing camera res to counteract motion blur
2025-11-23 cam driver
2025-12-03 new finger
2025-12-04 new cad models
    [zima_arm_elbow_to_wrist.FCStd, zima_arm_wrist_to_hand.FCStd, zima_arm_wrist_to_handv2.FCStd]
2025-12-07 arm IK pipeline updates
    [5dof_arm_ikpy.urdf]
2025-12-07 Forward Kinematics done
2025-12-08 updated freecad docs
    [996R_Mount.FCStd, zima_arm_elbow_to_wrist.FCStd, zima_arm_wrist_to_handv2.FCStd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]
2025-12-09 camera driver error suppress
2025-12-09 no timer
2025-12-09 limit gripper
2025-12-09 moving to hardware
    locked
    rate limitnig
    smaller safety
    gripper
    gripper
    limits
    typo
    less limit
    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
    [joy_control.py]
2025-12-09 exhaustive button list
2025-12-09 track directions
2025-12-09 limits for 20hz
2025-12-09 motor 3 bug in firmwarte
    [joy_control.py, servo_control.h]
2025-12-09 arm resets
2025-12-09 motor 3 fix
2025-12-10 arm visualization
2025-12-10 visualization and servo feedback
2025-12-10 arm model tuning
2025-12-11 adding arm state limits
2026-01-03 camera driver updates
2026-01-03 camera indez
2026-01-04 camera driver improvements
2026-01-04 swap cameras
2026-01-04 arm solver
2026-01-25 burnt servo port
2026-01-25 trying to fix servos
    [zima_hardware_interface.ino]
2026-01-27 kinematics tuning
2026-01-27 arm tuning
